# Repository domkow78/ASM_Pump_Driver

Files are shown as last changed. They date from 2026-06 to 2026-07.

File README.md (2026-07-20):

# ASM_Pump_Driver
Simple driver for ASM type water pump

## Opis Aplikacji

Aplikacja dla Arduino Nano steruje przekaźnikiem pompy wody na podstawie pomiaru prądu przemiennego (`AC RMS`) z czujnika ACS724 ±2.5A (Pololu 4040) oraz prezentuje bieżący stan na wyświetlaczu OLED SSD1306 (I2C).

### Funkcjonalności:
- Odczyt sygnału analogowego z ACS724 (`A0`) i przeliczenie na prąd skuteczny `RMS`.
- Automatyczny pomiar napięcia zasilania Arduino i korekcja przeliczenia ADC.
- Uśrednianie pomiaru `Vcc`, aby ograniczyć wahania wskazań.
- Dynamiczne wyznaczanie punktu zerowego (`Vzero`) czujnika w każdym oknie pomiarowym.
- Martwa strefa eliminująca resztkowy szum przy zerowym prądzie.
- Sterowanie przekaźnikiem (`D8`) z użyciem histerezy (oddzielny próg załączenia i wyłączenia).
- Wyświetlanie na OLED:
	- prądu skutecznego `Irms` w amperach,
	- napięcia zasilania `Vcc`,
	- stanu wyjścia przekaźnika (`ON`/`OFF`).

### Podłączenie:
- Przekaźnik -> `D8`
- Czujnik ACS724 ±2.5A (wyjście analogowe) -> `A0`
- OLED SSD1306 (I2C) -> `SDA/SCL`

### Działanie:
1. Aplikacja inicjalizuje wyświetlacz OLED oraz wyjście przekaźnika.
2. W pętli głównej przez okno ~`200 ms` (10 okresów `50 Hz`) szybko próbkuje sygnał z ACS724.
3. Z próbek wyznacza dynamicznie `Vzero` (średnia) oraz prąd skuteczny `Irms`.
4. Logika histerezy działa na dwóch progach prądu:
	 - `threshold_on` — próg załączenia przekaźnika,
	 - `threshold_off` — próg wyłączenia przekaźnika.
5. Dzięki histerezie przekaźnik nie „klapie” przy sygnale blisko progu.
6. OLED pokazuje bieżący prąd `Irms`, `Vcc` oraz stan przekaźnika (`ON`/`OFF`).

### Strojenie progów histerezy:
Progi są wyrażone w amperach `RMS`, dlatego należy dobrać je do rzeczywistego poboru pompy.

Pompa pracuje w zakresie mocy `12–38 W` na `230 V AC`, co odpowiada prądowi skutecznemu:
- `12 W` → `Irms ≈ 0.052 A`
- `38 W` → `Irms ≈ 0.165 A`

Progi muszą być poniżej najniższego prądu pracy (`~0.052 A`), dlatego ustawiono:
- `threshold_on = 0.035` — pewne wykrycie pracy nawet przy `12 W`,
- `threshold_off = 0.02` — wyłączenie dopiero, gdy pompa faktycznie stoi.

Dodatkowe wskazówki:
- Zwiększ `threshold_on`, jeśli przekaźnik załącza się przy zbyt małym prądzie.
- Zmniejsz `threshold_off`, jeśli przekaźnik wyłącza się zbyt wcześnie.
- Zachowaj warunek: `threshold_on > threshold_off`.

> Uwaga: przy `12 W` sygnał to tylko ok. `21 mV RMS` na ACS724 (kilka LSB ADC), dlatego okno pomiarowe wydłużono do `200 ms`, aby lepiej uśrednić pomiar przy niskich mocach.

### Pomiar AC RMS, Vzero i czułość ACS724:
Czujnik ACS724 przy zerowym prądzie daje na wyjściu napięcie około połowy zasilania (`~Vcc/2`). Przy prądzie przemiennym sygnał oscyluje wokół tego punktu, dlatego pojedynczy odczyt nie ma sensu — liczona jest wartość skuteczna `RMS`.

Punkt zerowy `Vzero` jest wyznaczany dynamicznie jako średnia próbek w oknie pomiarowym, co eliminuje dryf offsetu. Prąd skuteczny liczony jest według wzoru:
- `Irms = sqrt(mean(V^2) - mean(V)^2) / sensitivity`

Aktualnie w kodzie ustawiono:
- `acs724SensitivityVoltsPerAmp = 0.400`

To odpowiada wersji `ACS724 ±2.5A (Pololu 4040)` o czułości `400 mV/A`. Dodatkowo martwa strefa `currentDeadZoneAmps = 0.05` wymusza wskazanie `0 A` poniżej tego progu, aby wyeliminować szum.

### Kalibracja pomiaru ADC:
Kod automatycznie mierzy napięcie zasilania Arduino (`Vcc`) z użyciem wewnętrznego źródła odniesienia mikrokontrolera i wykorzystuje ten wynik do przeliczenia odczytu ADC. Przy zasilaniu z USB napięcie odniesienia często nie wynosi idealnie `5.000 V`, więc taka korekcja ogranicza błąd wskazania na OLED.

Dla pierwszego uruchomienia zmierzono:
- zasilanie Arduino z USB: `4.737 V`,
- napięcie na wejściu ADC: `2.367 V`.

Układ powinien teraz sam reagować na zmianę napięcia zasilania i odpowiednio korygować przeliczanie wartości z wejścia `A0`.

Ponieważ wewnętrzne źródło odniesienia AVR nie ma idealnie `1.100 V`, w kodzie dodano kalibrację stałej:
- `bandgapReferenceMillivolts = 1068`

Wartość została wyliczona z pomiaru:
- rzeczywiste `Vcc`: `4.689 V`,
- wskazanie OLED przed kalibracją: `4.829 V`.

Wzór do kolejnej korekty:
- `nowa_stala = stara_stala * (Vcc_rzeczywiste / Vcc_wyswietlane)`

Dla tego przypadku:
- `1068 ≈ 1100 * (4.689 / 4.829)`

Uwagi:
- mechanizm działa dla klasycznego Arduino Nano z mikrokontrolerem `ATmega328P`,
- dokładność zależy od tolerancji wewnętrznego źródła odniesienia, więc do pomiarów dokładnych nadal warto porównać wynik z multimetrem,
- `Vcc` używane do przeliczenia ADC jest uśredniane w oknie 8 ostatnich pomiarów,
- bieżące `Vcc` jest pokazywane na OLED i w `Serial`.

### Wymagane biblioteki:
- `Wire.h`
- `Adafruit_GFX.h`
- `Adafruit_SSD1306.h`

### Użycie:
Aby uruchomić aplikację:
1. Podłącz elementy zgodnie z sekcją „Podłączenie”.
2. Wgraj [src/asm_pump_driver/asm_pump_driver.ino](src/asm_pump_driver/asm_pump_driver.ino) na Arduino Nano.
3. Obserwuj prąd `Irms` i stan przekaźnika na OLED.
4. Dostosuj progi histerezy w kodzie do rzeczywistego poboru prądu pompy.

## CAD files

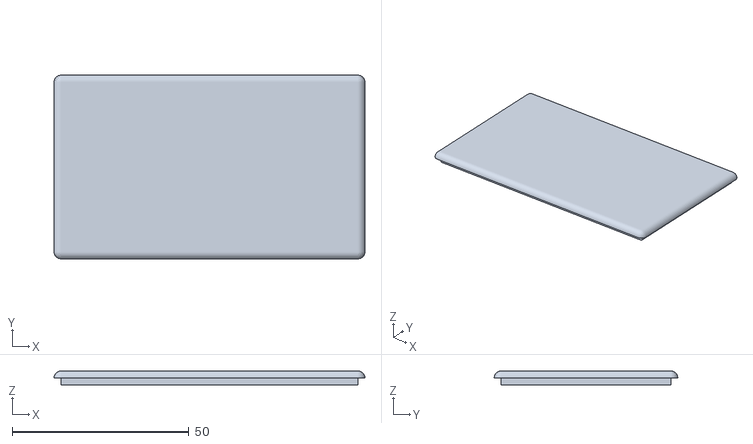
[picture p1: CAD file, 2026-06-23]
doc/3d models cover/Universla_Box_Bottom/Universla_Box_Top.stl
88.0 x 52.0 x 4.00

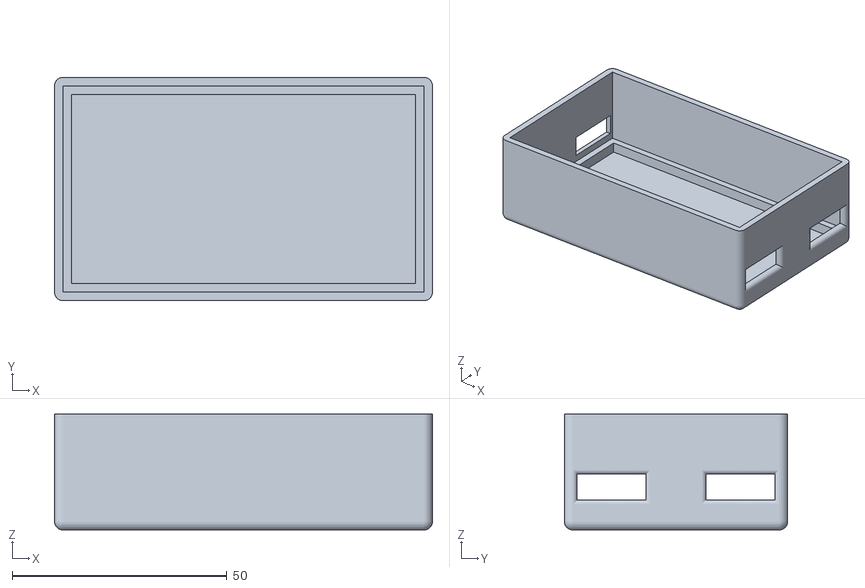
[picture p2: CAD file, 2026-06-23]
doc/3d models cover/Universla_Box_Bottom/Universla_Box_Bottom.stl
88.0 x 52.0 x 27.0

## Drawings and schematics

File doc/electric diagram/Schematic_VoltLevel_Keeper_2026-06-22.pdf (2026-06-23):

# POWER SUPPLYAUX

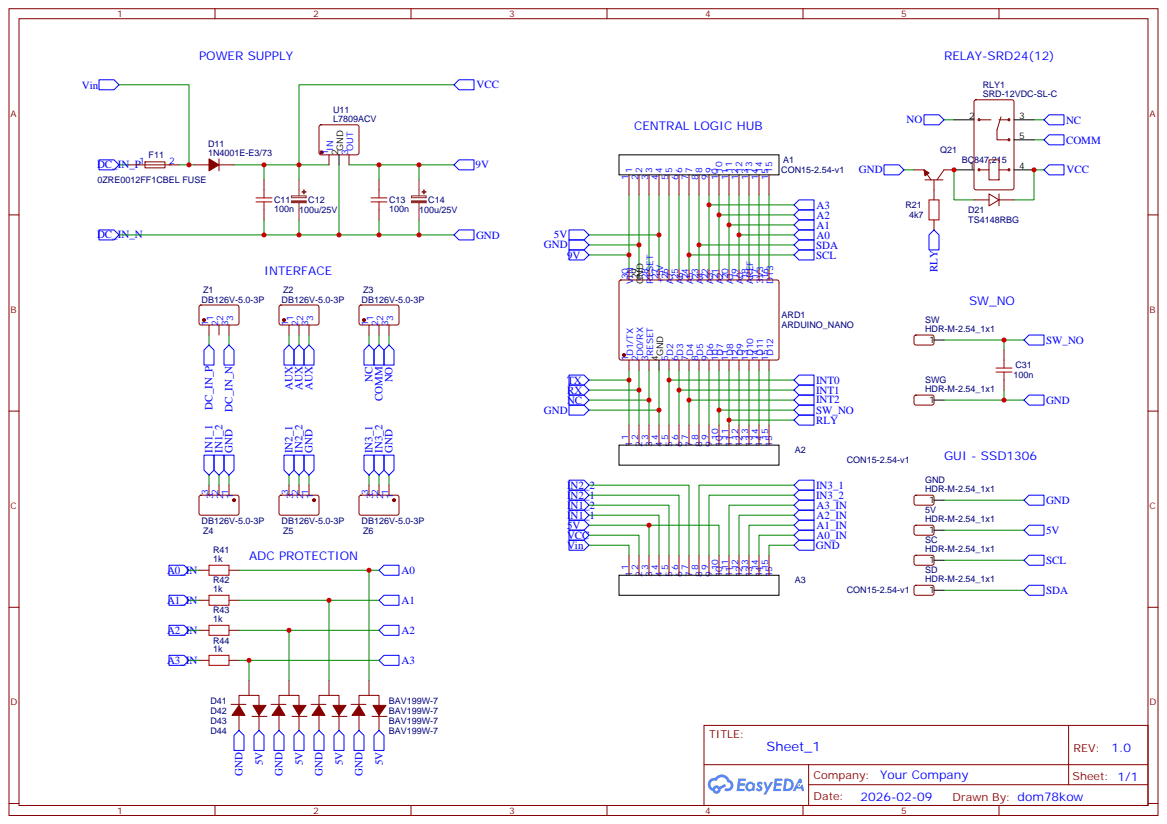
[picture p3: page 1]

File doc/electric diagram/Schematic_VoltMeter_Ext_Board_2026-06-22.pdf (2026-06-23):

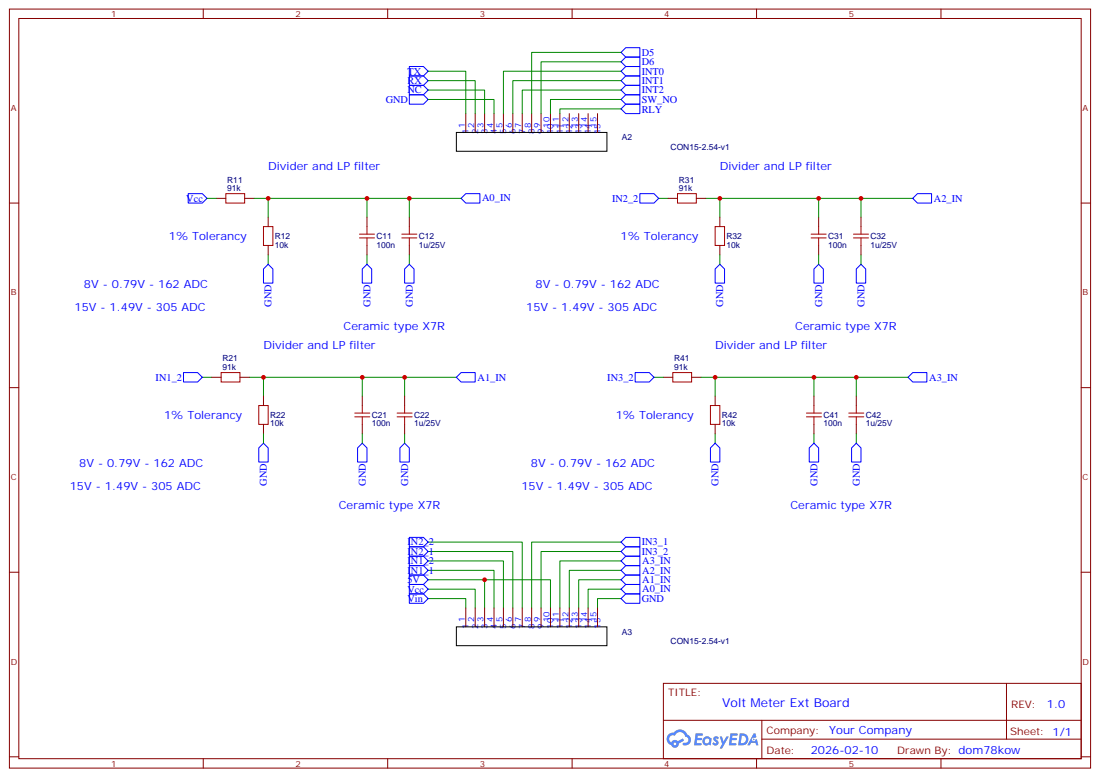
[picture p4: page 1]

Divider and LP filter

Divider and LP filterGND

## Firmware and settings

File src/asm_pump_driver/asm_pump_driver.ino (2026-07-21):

// Include necessary libraries
#include <Wire.h>
#include <Adafruit_GFX.h>
#include <Adafruit_SSD1306.h>

// Define pin connections
const int relayPin = 8;  // Relay connected to pin D8
const int ledPin    = 13; // Status LED connected to D13
const int sensorPin = A0; // ACS724 -2.5A..+2.5A (Pololu 4040) connected to pin A0
const long bandgapReferenceMillivolts = 1068; // Calibrated internal 1.1V reference for this Nano
const float zeroOffsetVoltage = 2.345; // ACS724 output voltage at zero current (~Vcc/2)
const float acs724SensitivityVoltsPerAmp = 0.400; // ACS724 +/-2.5A (Pololu 4040) = 400 mV/A

// AC RMS measurement parameters (mains 50 Hz -> 20 ms per period)
const unsigned long rmsWindowMs = 200; // 10 full periods at 50 Hz for better averaging
const float currentDeadZoneAmps = 0.01; // Ignore residual noise below this value

// Hysteresis parameters in amperes RMS.
// Pump power range 12-38W on 230V AC -> Irms ~ 0.052 A (12W) .. 0.165 A (38W).
// Thresholds must be below the lowest running current (~0.052 A).
const float threshold_on = 0.035; // Current (A) to turn relay ON (pump running)
const float threshold_off = 0.02; // Current (A) to turn relay OFF (pump stopped)
bool relayState = false; // Current relay state

// --- Simple activity detection (mean absolute deviation) ---
// Instead of computing a precise RMS current, we sample the sensor fast,
// subtract the resting value (~Vcc/2) and average the absolute deviation.
// This is robust to inverter frequency changes and needs no accurate
// current calibration. If the averaged deviation exceeds a threshold,
// the pump is considered running.
const unsigned long activityWindowMs = 30;   // Averaging window (20-50 ms)
const unsigned long activitySampleIntervalUs = 250; // ~4 kHz sampling (2-5 kHz)
// Thresholds are expressed in ADC counts of mean absolute deviation.
const float activityThresholdOn  = 8.0; // Deviation to turn relay ON (pump running)
const float activityThresholdOff = 4.0; // Deviation to turn relay OFF (pump stopped)

// Rolling average for Vcc measurement
const int VCC_WINDOW_SIZE = 8;
long      vccReadings[VCC_WINDOW_SIZE];
int       vccReadIndex   = 0;
int       vccSampleCount = 0;
long      vccReadingSum  = 0;

// Create an instance of the OLED display
Adafruit_SSD1306 display(128, 64, &Wire, -1);

long readVccMillivolts() {
#if defined(__AVR_ATmega328P__) || defined(__AVR_ATmega168__)
    ADMUX = _BV(REFS0) | _BV(MUX3) | _BV(MUX2) | _BV(MUX1);
    delay(2);
    ADCSRA |= _BV(ADSC);
    while (bit_is_set(ADCSRA, ADSC)) {
        ;
    }

    uint8_t low = ADCL;
    uint8_t high = ADCH;
    long reading = (high << 8) | low;

    return (bandgapReferenceMillivolts * 1023L) / reading;
#else
    return 5000L;
#endif
}

float updateAverageVccVoltage(long vccMillivolts) {
    vccReadingSum -= vccReadings[vccReadIndex];
    vccReadings[vccReadIndex] = vccMillivolts;
    vccReadingSum += vccReadings[vccReadIndex];
    vccReadIndex = (vccReadIndex + 1) % VCC_WINDOW_SIZE;

    if (vccSampleCount < VCC_WINDOW_SIZE) {
        vccSampleCount++;
    }

    return (vccReadingSum / (float)vccSampleCount) / 1000.0;
}

// Measure AC RMS current over a fixed window.
// Vzero is derived dynamically as the mean of the samples, which removes
// offset drift. Returns RMS current in amperes.
float measureRmsCurrent(float adcReferenceVoltage) {
    unsigned long startMs = millis();
    unsigned long sampleCount = 0;
    float sum = 0.0;         // Sum of sample voltages (for dynamic Vzero)
    float sumSquares = 0.0;  // Sum of squared sample voltages

    // First pass: collect sum and sum of squares of the sensor voltage.
    while (millis() - startMs < rmsWindowMs) {
        float v = (analogRead(sensorPin) / 1023.0) * adcReferenceVoltage;
        sum += v;
        sumSquares += v * v;
        sampleCount++;
    }

    if (sampleCount == 0) {
        return 0.0;
    }

    float mean = sum / sampleCount;                       // Dynamic Vzero
    float meanSquares = sumSquares / sampleCount;
    float variance = meanSquares - (mean * mean);         // RMS of AC component
    if (variance < 0.0) {
        variance = 0.0;
    }

    float vRms = sqrt(variance);
    float iRms = vRms / acs724SensitivityVoltsPerAmp;

    if (iRms < currentDeadZoneAmps) {
        iRms = 0.0;
    }

    return iRms;
}

// Simple pump-activity detection based on mean absolute deviation.
// 1. Sample the ADC fast (a few kHz).
// 2. Subtract the resting value (~Vcc/2, computed as the mean of samples).
// 3. Accumulate the absolute deviation of each sample.
// 4. Average over a short window (20-50 ms).
// Returns the mean absolute deviation in ADC counts.
float measurePumpActivity() {
    unsigned long startMs = millis();
    unsigned long sampleCount = 0;
    long sum = 0;               // Sum of raw ADC values (for resting value)
    int samples[300];           // Buffer for one window (max ~300 samples)
    const int maxSamples = 300;

    // First pass: collect raw samples at a fixed rate.
    while ((millis() - startMs < activityWindowMs) && (sampleCount < maxSamples)) {
        int raw = analogRead(sensorPin);
        samples[sampleCount] = raw;
        sum += raw;
        sampleCount++;
        delayMicroseconds(activitySampleIntervalUs);
    }

    if (sampleCount == 0) {
        return 0.0;
    }

    // Resting value = mean of the samples (dynamic, removes offset drift).
    float mean = (float)sum / sampleCount;

    // Second pass: accumulate absolute deviation from the resting value.
    float sumAbsDeviation = 0.0;
    for (unsigned long i = 0; i < sampleCount; i++) {
        sumAbsDeviation += fabs(samples[i] - mean);
    }

    return sumAbsDeviation / sampleCount;
}

void setup() {
    // Initialize serial output for debugging
    Serial.begin(115200);
    while (!Serial) {
        ;
    }

    // Initialize the relay pin and status LED
    pinMode(relayPin, OUTPUT);
    digitalWrite(relayPin, LOW); // Ensure relay is off initially
    pinMode(ledPin, OUTPUT);
    digitalWrite(ledPin, LOW);   // Ensure LED is off initially

    Serial.println("ASM Pump Driver start");

    // Initialize the OLED display
    display.begin(SSD1306_SWITCHCAPVCC, 0x3C);
    display.clearDisplay();
    display.setTextSize(1);
    display.setTextColor(SSD1306_WHITE);
    display.setCursor(0, 0);
    display.print("Monitoring current...");
    display.display();

    Serial.println("OLED initialized");
}

void loop() {
    // 1. Measure supply voltage Vcc
    long vccMillivolts = readVccMillivolts();
    float rawVccVoltage = vccMillivolts / 1000.0;
    float adcReferenceVoltage = updateAverageVccVoltage(vccMillivolts);

    // 2. Direct raw ADC reading on the sensor pin (control measurement)
    int rawAdcValue = analogRead(sensorPin);
    float adcVoltage = (rawAdcValue / 1023.0) * adcReferenceVoltage;

    // 3. Pump activity detection (mean absolute deviation, no RMS needed)
    float activity = measurePumpActivity();

    // Apply hysteresis logic on the activity value
    if (!relayState && activity > activityThresholdOn) {
        relayState = true;
        digitalWrite(relayPin, HIGH);
        digitalWrite(ledPin, HIGH);
    } else if (relayState && activity < activityThresholdOff) {
        relayState = false;
        digitalWrite(relayPin, LOW);
        digitalWrite(ledPin, LOW);
    }

    // NOTE: current (RMS) measurement temporarily disabled
    // float currentAmps = measureRmsCurrent(adcReferenceVoltage);

    Serial.print("Vcc(avg): ");
    Serial.print(adcReferenceVoltage, 3);
    Serial.print(" V | Vcc(raw): ");
    Serial.print(rawVccVoltage, 3);
    Serial.print(" V | ADC: ");
    Serial.print(rawAdcValue);
    Serial.print(" (");
    Serial.print(adcVoltage, 3);
    Serial.print(" V) | Act: ");
    Serial.print(activity, 2);
    Serial.print(" | Relay: ");
    Serial.println(relayState ? "ON" : "OFF");

    // Update OLED display
    display.clearDisplay();
    display.setTextSize(1);
    display.setTextColor(SSD1306_WHITE);

    // Line 1: Vcc supply voltage
    display.setCursor(0, 0);
    display.print("Vcc: ");
    display.print(adcReferenceVoltage, 3);
    display.print(" V");

    // Line 2: direct raw ADC reading (control measurement)
    display.setCursor(0, 8);
    display.print("ADC: ");
    display.print(rawAdcValue);
    display.print(" (");
    display.print(adcVoltage, 3);
    display.print("V)");

    // Line 3: pump activity (mean absolute deviation)
    display.setCursor(0, 16);
    display.print("Act: ");
    display.print(activity, 2);

    // Line 7: relay state
    display.setCursor(0, 48);
    display.print("Relay: ");
    display.print(relayState ? "ON" : "OFF");

    // Line 8: hysteresis thresholds
    display.setCursor(0, 56);
    display.print("ON:");
    display.print(activityThresholdOn, 1);
    display.print(" OFF:");
    display.print(activityThresholdOff, 1);

    display.display();

    delay(1000); // Delay for stability
}

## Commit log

2026-06-23 basic doc
    [Universla_Box_Bottom.stl, Universla_Box_Top.stl]
2026-07-02 d13 added to led signal
2026-07-20 auto measurements power voltage
2026-07-20 Vref calibration
2026-07-20 adjustment for BLDC 20W
2026-07-21 row measurement, only voltage
